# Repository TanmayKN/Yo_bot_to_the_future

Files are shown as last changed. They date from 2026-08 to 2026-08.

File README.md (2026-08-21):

<!-- Add the team photo here once it is in t-photos/, like this:
![Team Yo_Bot_To_The_Future](t-photos/team_photo.jpg)
-->

# Yo_Bot_To_The_Future

**WRO Future Engineers 2026, Self-Driving Cars**

GitHub repository and vehicle design for Team Yo_Bot_To_The_Future, Yolabs Academy.

---

## Table of Contents

- [Overview](#overview)
- [Repository Structure](#repository-structure)
- [Key Features](#key-features)
- [Key Folders](#key-folders)
- [Meet the Team](#meet-the-team)
- [Hardware](#hardware)
- [Mobility System](#mobility-system)
- [Power System](#power-system)
- [Sensing and Vision](#sensing-and-vision)
- [Software](#software)
  * [Development Environment](#development-environment)
  * [Libraries and Dependencies](#libraries-and-dependencies)
  * [Open Round](#open-round)
  * [Obstacle Round](#obstacle-round)
  * [Seeing the Pillars](#seeing-the-pillars)
  * [Failure Handling](#failure-handling)
  * [Getting the Code Running](#getting-the-code-running)
  * [Tuning and Testing](#tuning-and-testing)
- [Safety](#safety)

---

## Overview

This repository holds the hardware, the software and all the supporting material for our WRO Future Engineers 2026 vehicle. It is a 1/10 scale self driving car that drives around a walled track it has never seen before, keeps itself straight, and in the obstacle round passes red and green pillars on the correct side.

**There is one controller on this car and it is an ESP32.** No second computer, no companion board, nothing else running code. A camera usually needs a computer attached to it to make sense of what it sees, and that is normally what forces teams into a two board setup. We avoided that by using a camera that already has a processor inside it. The HuskyLens does its own colour recognition on its own chip and sends the ESP32 nothing but a handful of numbers over I2C. The picture never leaves the camera.

That one decision made a lot of other things easier. Nothing is competing with us for control of the timing, there is no boot sequence to wait through before the car is ready, there is no extra battery branch to plan around, and there is no link between two boards that can shake loose halfway through a run. What we gave up is the ability to write our own image processing code, and we were happy to trade that for a frame rate that stays the same every single time.

We run two separate programs, one for each round, rather than one program that tries to do both. The open round never needs to see a pillar, so loading it with vision code would only give it more ways to go wrong.

---

## Repository Structure

| Directory | What is inside |
| --- | --- |
| [`src/`](src/) | The ESP32 code. One program for the open round and one for the obstacle round. |
| [`models/`](models/) | STL files for every part we 3D printed, including the chassis, the cages, the wheel covers and the HuskyLens mount. |
| [`schemes/`](schemes/) | Wiring diagrams and pinout diagrams for both rounds. |
| [`t-photos/`](t-photos/) | Photos of the team. |
| [`v-photos/`](v-photos/) | Photos of the finished car from the front, back, both sides, top and bottom. |
| [`video/`](video/) | A link to our driving footage. Being filmed, going up soon. |
| [`docs/`](docs/) | The full engineering documentation. |

---

## Key Features

**One board runs the whole car.** The ESP32 reads every sensor, decides what to do, and drives the motor and the steering itself. Putting the vision inside the camera instead of on a separate computer removed a whole set of timing and power problems before they could happen.

**You can actually rebuild it from this repo.** Every printed part is here as an STL, every wire is on the diagram, and every choice we made has the reason written next to it. You should not have to guess at anything or design a part yourself.

**Two different ways of sensing the track.** The IMU tells us which way we are pointing and the ultrasonic sensors tell us where the walls are. They go wrong in completely different situations, so when one gets confused the other usually still works.

**Built for the actual rules.** The code, the wiring and the chassis are all designed around the WRO Future Engineers rules, including proper Ackermann steering on a steered front axle instead of taking the easy way out with skid steering.

---

## Key Folders

**[`src/`](src/)** has both programs, written in C++ for the Arduino framework. `open_round.ino` handles the three lap open challenge and `obstacle_challenge.ino` handles the pillar round.

**[`models/`](models/)** has every 3D printed part as an STL, ready to drop into a slicer. The chassis is meant to be printed in PETG at 30 percent honeycomb infill.

**[`schemes/`](schemes/)** has the wiring diagram for each round plus a pinout diagram showing which GPIO does what.

**[`v-photos/`](v-photos/)** has photos of the finished car from every angle. They are meant to be used as a build reference, so you can see where things actually sit and how the wires are routed instead of working from the diagram alone.

---

## Meet the Team

- **Team:** Yo_Bot_To_The_Future
- **Country:** India
- **City:** Bengaluru, Karnataka
- **Academy:** Yolabs
- **Mentor:** Rahul Sharma

| Member | School | Grade |
| --- | --- | --- |
| Vedant | Greenwood High International School | 9 |
| Tanmay | Greenwood High International School | 9 |
| Anshuman | Primus Public School | 9 |

All three of us are in Grade 9 and based in Bengaluru, and we build at Yolabs Academy under our mentor Rahul Sharma.

Two of us are from Greenwood High and one is from Primus, so we could not just meet up after class every day and work on it together. That meant we had to actually split the work up and agree on who was doing what, instead of all three of us poking at the same thing at once.

Vedant did the 3D design work, so every printed part on the car came out of his CAD files, and he also wrote the documentation and was on build duty. Tanmay wrote the code and also worked on putting the car together. Anshuman did a huge amount of the actual building, and a lot of the car physically existing is down to him.

The build itself was the part all three of us ended up working on together, which made sense, because it is the part where you find out whether the design and the code actually agree with each other.

---

## Hardware

Before building anything we worked out what parts we needed and why. Every component on this list is doing a specific job. Nothing here is just whatever we had lying around.

| Component | What it does |
| --- | --- |
| **ESP32 WROOM-32 DevKit V1** | The only controller on the car. It reads every sensor, decides what to do, and drives the motor and steering. |
| **HuskyLens AI camera** | The vision system, used in the obstacle round. Its own chip spots the coloured pillars and sends back just their position, so the ESP32 never deals with picture data. |
| **BNO055 IMU** | Tells us which way the car is facing. This is the main sensor the steering works from, and it is what stops small errors from adding up into the car driving crooked. |
| **DC drive motor** | Drives the rear wheels through the L298N. Speed is set in software as a PWM value rather than running flat out. |
| **Steering servo** | Steers the front wheels. Centre is 90 degrees with a usable range of roughly 28 to 142. |
| **PCA9685 servo driver** | Fitted to the car and sitting on the I2C bus. See the note under [Mobility System](#mobility-system) about how the steering is currently driven. |
| **3× HC-SR04 ultrasonic sensors** | Mounted front, left and right to measure how far away the walls are. The front one decides when to turn, the side ones tell us which way the track opens up. |
| **L298N motor driver** | Takes the small signals from the ESP32 and switches the much bigger current the motor needs, in both directions. |
| **LM2596 buck converters** | Drop the battery voltage down to a clean supply for the servo and the electronics, on separate branches. |
| **3S 18650 pack** | Three cells in series, about 11.1 V normally and 12.6 V when full, with a BMS. |

Other bits: PETG filament, M3 standoffs and screws, perfboard, and resistors for the voltage dividers on the ECHO lines.

---

## Mobility System

**Steering.** The front wheels are steered through an Ackermann linkage. Centre is 90 degrees, and the code clamps the travel to between 28 and 142 degrees so the linkage can never be driven into its own hard stops.

> **Note on the PCA9685.** The board is fitted and wired onto the I2C bus, but in the firmware as it stands the steering pulse is generated by the ESP32 itself on GPIO 4 using the `ESP32Servo` library. Both programs create a `Servo` object and call `attach(4)`, and neither one includes a PCA9685 library or writes to it. So the driver is present on the car but is not what moves the steering right now. If you are rebuilding from this repo, wire the servo signal to GPIO 4 and it will work.

**Drive.** A DC motor drives the rear axle through the L298N, so steering and power are separate jobs and neither has to compromise for the other. Speed is a PWM value between 0 and 255. We cruise at 150 in the open round and 135 in the obstacle round, and drop to 120 when reversing.

**Why Ackermann.** This is the same steering real cars use. When a car turns, the inside wheel is going around a tighter circle than the outside wheel. If you turn both wheels by the same amount, one of them has to slide sideways across the ground to keep up. Ackermann turns the inside wheel further than the outside one, so both wheels roll cleanly around the same point. The other option, skid steering, makes the wheels slide on purpose, and all that sliding creates friction that changes from run to run. Once that happens you can no longer predict where the car will end up. The linkage is built to satisfy this:

```
cot(Outer_Angle) - cot(Inner_Angle) = Track_Width / Wheelbase
```

**Why we do not just drive flat out.** The HuskyLens gives us a limited number of frames per second. The faster the car moves, the further it travels between one frame and the next, which means every decision about a pillar is based on a picture of where things were a moment ago. Slowing the car down until it matches the camera is easier and more reliable than trying to speed the camera up. The same logic applies to the ultrasonics, which need time for the sound to travel out and come back.

---

## Power System

The car runs on three lithium ion cells in series, which is about 11.1 V normally and 12.6 V when fully charged. The power splits right after a master fuse and a kill switch into branches that do not share a wire.

```mermaid
flowchart LR
    BAT[3S 18650 pack<br/>12.6V full] --> FUSE[Master fuse<br/>+ kill switch]

    FUSE -->|raw 12.6V| L298[L298N driver]
    L298 --> MOT[Drive motor]

    FUSE -->|buck| SRV[Steering servo]
    FUSE -->|buck to 5V| ESP[ESP32]
    FUSE -->|buck to 5V| HL[HuskyLens]
```

**Why separate branches.** The motor wants the full battery voltage and pulls a lot of current when it speeds up. The servo briefly pulls over an amp if it pushes against something and gets stuck. If either of those shared a wire with the electronics, the voltage would dip enough to reset the ESP32 in the middle of a run. The annoying part is that this looks exactly like a software bug when you are trying to find it.

**Something worth knowing if you rebuild this:** the HuskyLens pulls around 320 mA while it is working. That is more than you want to run through the ESP32's own 5 V pin, so it should be fed from the regulated supply instead.

---

## Sensing and Vision

```mermaid
flowchart LR
    UL[Left ultrasonic] --> ESP[ESP32]
    UF[Front ultrasonic] --> ESP
    UR[Right ultrasonic] --> ESP

    HL[HuskyLens] -->|I2C, block coords| ESP
    IMU[BNO055] -->|I2C| ESP
    PCA[PCA9685] -.->|I2C, fitted| ESP
    ESP -->|GPIO 4 PWM| SRV[Steering servo]
    ESP --> L298[L298N] --> MOT[Drive motor]
```

**BNO055 IMU.** This is the sensor the steering really works from. It does its own sensor fusion and gives us a heading straight out, so we are not writing filter code ourselves. Steering by heading rather than by wall distance means the car keeps going straight even when a wall reading is briefly wrong.

**Ultrasonics.** One at the front and one on each side. The front sensor decides when a wall is close enough to turn at, and the side sensors tell us which way the track opens up so we know which direction to turn. They also catch the case where the car is about to hit something and needs to back up.

**HuskyLens.** Used in the obstacle round only, mounted on a printed bracket so it can see the pillars ahead. It sits on the I2C bus alongside the IMU and the PCA9685.

**A wiring warning.** The ECHO pins on the HC-SR04 put out 5 V, and the ESP32's pins can only take 3.3 V. Every ECHO line goes through a voltage divider. If you skip this you will damage the board.

### Pin map

Both programs use the same wiring, so you do not have to change anything on the car between rounds.

| Function | ESP32 pin |
| --- | --- |
| Motor direction | GPIO 13, GPIO 12 |
| Motor PWM | GPIO 25 |
| Steering servo signal | GPIO 4 |
| Front ultrasonic TRIG / ECHO | GPIO 5 / 18 |
| Right ultrasonic TRIG / ECHO | GPIO 17 / 16 |
| Left ultrasonic TRIG / ECHO | GPIO 26 / 27 |
| Start button | GPIO 15, active low |
| I2C bus for BNO055, HuskyLens and PCA9685 | GPIO 21 SDA, GPIO 22 SCL |

`Wire.begin()` is called with no arguments in both programs, which is what puts the I2C bus on GPIO 21 and 22. Everything shares one common ground.

---

## Software

### Development Environment

| Part | Language | Written and flashed with |
| --- | --- | --- |
| ESP32 | C++ / Arduino | Arduino IDE 2.0 or newer, with the ESP32 board package by Espressif |

The board is set up as an **ESP32 Dev Module**, with the serial monitor at 115200.

### Libraries and Dependencies

| Library | Used by | Why it is needed |
| --- | --- | --- |
| `Adafruit_BNO055` and `Adafruit_Sensor` | Both | Reads the heading out of the IMU. |
| `ESP32Servo` | Both | Generates the steering pulse straight off a GPIO pin. |
| `Wire` | Both | I2C. Already comes with the Arduino IDE. |
| `HUSKYLENS` | Obstacle round | Talks to the camera over I2C and turns what comes back into something we can use. |
| `WiFi` | Open round | Only used for the optional telnet debug link. |

### Open Round

Three laps around an empty track, then back to where it started.

The car steers by heading rather than by wall distance. The BNO055 gives us the angle we are actually pointing at, we compare it to the angle we want, and a **PI controller** turns that difference into a small steering correction:

```
Error      = Target_Heading - Current_Heading
Correction = GAIN_P * Error + GAIN_I * Integral(Error)
```

`GAIN_P` is 6.0 and decides how hard the car reacts to being off angle right now. `GAIN_I` is 0.2 and slowly removes any drift that builds up over a lap. The correction is capped at 22 degrees so a bad reading can never throw the steering hard over, and the integral has its own separate cap of 150 to stop it winding up. Any error under 0.6 degrees counts as straight and gets ignored, otherwise the car would twitch constantly.

There is no D term. On a car this size the P and I terms were enough, and adding D mostly amplified noise.

The front ultrasonic decides when to corner. Below 65 cm the car commits to a turn, and the side sensors decide which way by looking for the gap over 90 cm. Below 25 cm the car has got too close, so it reverses for about 700 ms and tries again. The PI controller is switched off during a corner, because during a deliberate turn a large heading error is correct and letting the controller fight it would only make the turn worse.

Once three laps are done the car switches into homing mode, which is the same wall following with looser thresholds, and stops when the front distance comes back within 5 cm of what it measured at the start line.

```mermaid
flowchart TD
    A([Power on]) --> B[Wait for START over serial]
    B --> C[Read heading and<br/>all three ultrasonics]
    C --> H{homingMode?}
    H -->|Yes| HM[Head for the start line]
    HM --> C
    H -->|No| D{Front wall<br/>under 25 cm?}
    D -->|Yes| E[Reverse 700 ms]
    E --> C
    D -->|No| F{Front under 65 cm and<br/>one side open over 90 cm?}
    F -->|Yes| G[Back up, corner left or right]
    G --> C
    F -->|No| I[Cruise at PWM 150,<br/>PI controller holds heading]
    I --> C
```

### Obstacle Round

Same track, now with red and green pillars that have to be passed on the correct side.

The program runs as a two state machine. While the state is `STRAIGHT` the camera gets a say. Once the car commits to a turn the state becomes `TURNING` and the camera is ignored completely until the turn is finished, because half a decision from a camera partway through a turn is worse than no decision at all.

When the camera reports a pillar that is close enough to matter, the car overrides its normal steering and shifts to one side to go around it, then hands control back once it is past. Two numbers decide whether a pillar counts. `HUSKY_AREA_TRIGGER` is 3000 and is how big the pillar has to look before the car commits to a full dodge, since a bigger block means a closer pillar. `HUSKY_SOFT_TRIGGER` is 150 and catches pillars that are further away, so the car can start lining up early instead of swerving at the last second.

After a pillar is dealt with there is a cooldown of roughly 1.8 seconds before the car will react to another one. Without it, the same pillar gets seen again on the next frame and the car tries to avoid something it has already passed. If a wall turns up while that cooldown is still running, the car creeps forward slowly rather than turning, and if it ends up jammed against the wall it reverses out.

Before a turn actually starts there is a second gate. The car stops, reads the wall again to confirm, and checks one last time that no pillar is in view. If either check fails the turn is abandoned. The run ends after 12 turns, which is three laps of a four cornered track.

### Seeing the Pillars

The HuskyLens is used in Colour Recognition mode with three colours taught to it:

| ID | Colour | What it means |
| --- | --- | --- |
| 1 | Green | Pass on one side |
| 2 | Red | Pass on the other side |
| 3 | Magenta | The parking lot, ignored during normal driving |

It saves these in its own memory, so they stay there after the power is turned off and we do not have to teach it again every time.

Each frame it sends back the biggest matching patch of colour as a block, which is an ID, a centre X, a centre Y, a width and a height. The ESP32 gets two useful things out of that. The centre X tells us which side of the frame the pillar is on, measured against 160 on a 320 pixel wide image. The size of the block tells us roughly how far away it is. Between the soft and the hard trigger the steering nudge is scaled from 8 to 35 degrees depending on both, so a pillar that is far away and near the middle barely moves the wheels while one that is close and off to the side gets a firm response.

Because the camera does the recognising itself, it works on hue rather than raw RGB, which holds up much better when the lighting at the venue is not the lighting we practised in.

### Failure Handling

Most of what went wrong in testing was not the car making a bad decision. It was the car making a decision based on information that was no longer true.

- **A wall reading that makes no sense.** Ultrasonic sound that hits a wall at a sharp angle never comes back, and the sensor just times out. Because the car steers by IMU heading and not by wall distance, one bad reading does not move the steering at all. It only affects when the car decides to corner, and the obstacle program reads the wall a second time to confirm before committing.
- **Getting too close to a wall.** The car stops trying to steer out of it, reverses, and starts again. Trying to steer out of a corner you are already in usually just wedges the car in harder.
- **Seeing the same pillar twice.** The cooldown after an avoidance stops the car reacting again to a pillar it has already gone around.
- **Lighting changes.** Arena lighting washes the colours out. The fix is to teach the colours again once we get to the venue, under the lights we are actually going to run under.

### Getting the Code Running

1. Clone the repo and open either `src/open_round.ino` or `src/obstacle_challenge.ino` in the Arduino IDE.
2. Install the libraries listed above through the Library Manager.
3. For the obstacle round, go into the HuskyLens settings menu and set the protocol to **I2C**. Put it in **Colour Recognition** mode and teach it green as ID 1, red as ID 2 and magenta as ID 3. Do this under the lighting you are actually going to run in.
4. Pick **ESP32 Dev Module** as the board, choose your serial port, and upload.
5. Open the serial monitor at 115200 and check the I2C devices are found.
6. Put the car up on blocks with the wheels off the ground. Check the motor spins the right way, the steering centres, and the IMU heading changes when you rotate the car by hand.
7. Send `START` over the serial monitor to begin the open round.

### Tuning and Testing

**What to tune, in this order:**

1. **Steering centre.** `STEER_CENTRE` is 94 in the open round and needs trimming for each car, because no two linkages come out identical. Get this right first, since everything else is built on top of a car that drives straight.
2. **Colour IDs.** Teach them again at the venue, every time. This is the number one reason pillars get missed.
3. **Pillar triggers.** `HUSKY_AREA_TRIGGER` decides how close a pillar gets before the car commits. Set it too low and the car swerves at pillars it has not even reached yet.
4. **PI gains.** `GAIN_P` first, until the car holds a straight line without weaving. Then `GAIN_I`, and keep it small, since its job is only to remove slow drift over a lap.
5. **Corner distances.** `RANGE_CORNER` at 65 cm decides when the car starts turning. Too late and it clips the wall, too early and it cuts the corner short.

The open round also has an optional telnet debug link over WiFi, so you can watch what the car is thinking while it drives instead of trailing a USB cable behind it. Put your network details in `WIFI_SSID` and `WIFI_PASS` and uncomment `startDebugLink()` in `setup()`.

---

## Safety

A 3S lithium battery holds enough energy to start a fire, and the steering has enough force to pinch a finger. These are the rules we work to.

- The pack is charged on a balance charger, on a surface that will not burn, never left alone and never inside a closed box.
- A master fuse sits on the positive wire from the battery, so a short further down blows the fuse instead of pushing the battery's full current through the wiring. The kill switch cuts every branch and can be reached from outside the chassis.
- The battery gets unplugged before any rewiring, and metal tools stay away from the battery terminals.
- Buck converters get checked with a multimeter before any board is plugged into them. One set wrong will kill the ESP32 and the HuskyLens instantly.
- Keep fingers away from the steering while the car is powered. The servo can jump without warning if the ESP32 resets.
- All motor code gets tested with the car up on blocks and the wheels off the ground.

The full list is in section 2.5 of the engineering documentation in [`docs/`](docs/).

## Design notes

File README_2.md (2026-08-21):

<!-- Add the team photo here once it is in t-photos/, like this:
![Team Yo_Bot_To_The_Future](t-photos/team_photo.jpg)
-->

# Yo_Bot_To_The_Future

**WRO Future Engineers 2026, Self-Driving Cars**

GitHub repository and vehicle design for Team Yo_Bot_To_The_Future, Yolabs Academy.

---

## Table of Contents

- [Overview](#overview)
- [Repository Structure](#repository-structure)
- [Key Features](#key-features)
- [Key Folders](#key-folders)
- [Meet the Team](#meet-the-team)
- [Hardware](#hardware)
- [Mobility System](#mobility-system)
- [Power System](#power-system)
- [Sensing and Vision](#sensing-and-vision)
- [Software](#software)
  * [Development Environment](#development-environment)
  * [Libraries and Dependencies](#libraries-and-dependencies)
  * [Open Round](#open-round)
  * [Obstacle Round](#obstacle-round)
  * [Seeing the Pillars](#seeing-the-pillars)
  * [Failure Handling](#failure-handling)
  * [Getting the Code Running](#getting-the-code-running)
  * [Tuning and Testing](#tuning-and-testing)
- [Safety](#safety)

---

## Overview

This repository holds the hardware, the software and all the supporting material for our WRO Future Engineers 2026 vehicle. It is a 1/10 scale self driving car that drives around a walled track it has never seen before, keeps itself straight, and in the obstacle round passes red and green pillars on the correct side.

**Everything runs on one board.** A camera normally needs a computer to go with it, so most teams add a single board computer to handle the obstacle round. We did it the other way around and used a camera that has a computer inside it. The HuskyLens does its own colour recognition on its own chip and only sends us back a few numbers over I2C. All the heavy work with the picture happens inside the camera, so our ESP32 never has to touch it.

That one choice made a lot of other things easier. There is no operating system fighting us for control of the timing, no waiting for a computer to boot before we can start, no extra battery branch to plan for, and no cable between two boards that can shake loose halfway through a run. What we gave up is the ability to write our own image code, and we were happy to trade that for a frame rate that stays the same every single time.

We run two separate programs, one for each round, rather than one program that tries to do both. The open round never needs to see a pillar, so loading it with vision code would only give it more ways to fail.

---

## Repository Structure

| Directory | What is inside |
| --- | --- |
| [`src/`](src/) | The ESP32 code. One program for the open round and one for the obstacle round. |
| [`models/`](models/) | STL files for every part we 3D printed, including the chassis, the cages, the wheel covers and the HuskyLens mount. |
| [`schemes/`](schemes/) | Wiring diagrams for both rounds, showing every part and how it all connects. |
| [`t-photos/`](t-photos/) | Photos of the team. |
| [`v-photos/`](v-photos/) | Photos of the finished car from the front, back, both sides, top and bottom. |
| [`video/`](video/) | A link to our driving footage. Being filmed, going up soon. |
| [`docs/`](docs/) | The full engineering documentation. |

---

## Key Features

**One controller for the whole car.** The ESP32 reads every sensor, decides what to do and drives the motor and steering itself. Vision lives inside the camera instead of on a second board, which removed a whole set of timing and power problems before they could happen.

**You can actually rebuild it from this repo.** Every printed part is here as an STL, every wire is on the diagram, and every choice we made has the reason written next to it. You should not have to guess at anything or design a part yourself.

**Two different ways of sensing the track.** The IMU tells us which way we are pointing and the ultrasonic sensors tell us where the walls are. They fail in completely different situations, so when one gets confused the other usually still works.

**Built for the actual rules.** The code, the wiring and the chassis are all designed around the WRO Future Engineers rules, including proper Ackermann steering on a steered front axle instead of taking the easy way out with skid steering.

---

## Key Folders

**[`src/`](src/)** has both programs, written in C++ for the Arduino framework. `open_round.ino` handles the three lap open challenge and `obstacle_challenge.ino` handles the pillar round.

**[`models/`](models/)** has every 3D printed part as an STL, ready to drop into a slicer. The chassis is meant to be printed in PETG at 30 percent honeycomb infill.

**[`schemes/`](schemes/)** has a wiring diagram for each round. They show the full power layout starting from the battery, which branch each part sits on, and which sensor lines need voltage dividers.

**[`v-photos/`](v-photos/)** has photos of the finished car from every angle. They are meant to be used as a build reference, so you can see where things actually sit and how the wires are routed instead of working from the diagram alone.

---

## Meet the Team

- **Team:** Yo_Bot_To_The_Future
- **Country:** India
- **City:** Bengaluru, Karnataka
- **Academy:** Yolabs
- **Mentor:** Rahul Sharma

| Member | School | Grade |
| --- | --- | --- |
| Vedant | Greenwood High International School | 9 |
| Tanmay | Greenwood High International School | 9 |
| Anshuman | Primus Public School | 9 |

All three of us are in Grade 9 and based in Bengaluru, and we build at Yolabs Academy under our mentor Rahul Sharma.

Two of us are from Greenwood High and one is from Primus, so we could not just meet up after class every day and work on it together. That meant we had to actually split the work up and agree on who was doing what, instead of all three of us poking at the same thing at once.

Vedant did the 3D design work, so every printed part on the car came out of his CAD files, and he also wrote the documentation and was on build duty. Tanmay wrote the code and also worked on putting the car together. Anshuman did a huge amount of the actual building, and a lot of the car physically existing is down to him.

The build itself was the part all three of us ended up working on together, which made sense, because it is the part where you find out whether the design and the code actually agree with each other.

---

## Hardware

Before building anything we worked out what parts we needed and why. Every component on this list is doing a specific job. Nothing here is just whatever we had lying around.

| Component | What it does |
| --- | --- |
| **ESP32 WROOM-32 DevKit V1** | The only controller on the car. It reads every sensor, decides what to do, and drives the motor and steering. |
| **HuskyLens AI camera** | The vision system, used in the obstacle round. Its own chip spots the coloured pillars and sends back just their position, so the ESP32 never deals with picture data. |
| **BNO055 IMU** | Tells us which way the car is facing. This is the main sensor the open round steers by, and it is what stops small errors from adding up into the car driving crooked. |
| **DC drive motor** | Drives the rear wheels through the L298N. Speed is set in software as a PWM value rather than running flat out. |
| **Steering servo** | Steers the front wheels, driven straight off the ESP32 with the `ESP32Servo` library. Centre is 90 degrees with a usable range of roughly 28 to 142. |
| **3× HC-SR04 ultrasonic sensors** | Mounted front, left and right to measure how far away the walls are. The front one decides when to turn, the side ones tell us which way the track opens up. |
| **L298N motor driver** | Takes the small signals from the ESP32 and switches the much bigger current the motor needs, in both directions. |
| **LM2596 buck converters** | Drop the battery voltage down to a clean supply for the servo and the electronics, on separate branches. |
| **3S 18650 pack** | Three cells in series, about 11.1 V normally and 12.6 V when full, with a BMS. |

Other bits: PETG filament, M3 standoffs and screws, perfboard, and resistors for the voltage dividers on the ECHO lines.

---

## Mobility System

**Steering.** The front wheels are steered through an Ackermann linkage. The servo is driven directly from GPIO 4 using `ESP32Servo`, with 90 degrees as centre.

**Drive.** A DC motor drives the rear axle through the L298N, so steering and power are separate jobs and neither has to compromise for the other. Speed is a PWM value between 0 and 255. We cruise at 150 in the open round and 135 in the obstacle round, and drop to 120 when reversing.

**Why Ackermann.** This is the same steering real cars use. When a car turns, the inside wheel is going around a tighter circle than the outside wheel. If you turn both wheels by the same amount, one of them has to slide sideways across the ground to keep up. Ackermann turns the inside wheel further than the outside one, so both wheels roll cleanly around the same point. The other option, skid steering, makes the wheels slide on purpose, and all that sliding creates friction that changes from run to run. Once that happens you can no longer predict where the car will end up. The linkage is built to satisfy this:

```
cot(Outer_Angle) - cot(Inner_Angle) = Track_Width / Wheelbase
```

**Why we do not just drive flat out.** The HuskyLens gives us a limited number of frames per second. The faster the car moves, the further it travels between one frame and the next, which means every decision about a pillar is based on a picture of where things were a moment ago. Slowing the car down until it matches the camera is easier and more reliable than trying to speed the camera up. The same logic applies to the ultrasonics, which need time for the sound to travel out and come back.

---

## Power System

The car runs on three lithium ion cells in series, which is about 11.1 V normally and 12.6 V when fully charged. The power splits right after a master fuse and a kill switch into branches that do not share a wire.

```mermaid
flowchart LR
    BAT[3S 18650 pack<br/>12.6V full] --> FUSE[Master fuse<br/>+ kill switch]

    FUSE -->|raw 12.6V| L298[L298N driver]
    L298 --> MOT[Drive motor]

    FUSE -->|buck| SRV[Steering servo]
    FUSE -->|buck to 5V| ESP[ESP32]
    FUSE -->|buck to 5V| HL[HuskyLens]
```

**Why separate branches.** The motor wants the full battery voltage and pulls a lot of current when it speeds up. The servo briefly pulls over an amp if it pushes against something and gets stuck. If either of those shared a wire with the electronics, the voltage would dip enough to reset the ESP32 in the middle of a run. The annoying part is that this looks exactly like a software bug when you are trying to find it.

**Something worth knowing if you rebuild this:** the HuskyLens pulls around 320 mA while it is working. That is more than you want to run through the ESP32's own 5 V pin, so it should be fed from the regulated supply instead.

---

## Sensing and Vision

```mermaid
flowchart LR
    UL[Left ultrasonic] --> ESP[ESP32]
    UF[Front ultrasonic] --> ESP
    UR[Right ultrasonic] --> ESP

    HL[HuskyLens] -->|I2C, block coords| ESP
    IMU[BNO055] -->|I2C| ESP
    ESP -->|GPIO 4| SRV[Steering servo]
    ESP --> L298[L298N] --> MOT[Drive motor]
```

**BNO055 IMU.** This is the sensor the open round is really built around. It does its own sensor fusion and gives us a heading straight out, so we are not writing filter code ourselves. Steering by heading rather than by wall distance means the car keeps going straight even when a wall reading is briefly wrong.

**Ultrasonics.** One at the front and one on each side. The front sensor decides when a wall is close enough to turn at, and the side sensors tell us which way the track opens up so we know which direction to turn. They also catch the case where the car is about to hit something and needs to back up.

**HuskyLens.** Used in the obstacle round only, mounted on a printed bracket so it can see the pillars ahead. It sits on the I2C bus alongside the IMU.

**A wiring warning.** The ECHO pins on the HC-SR04 put out 5 V, and the ESP32's pins can only take 3.3 V. Every ECHO line goes through a voltage divider. If you skip this you will damage the board.

### Pin map

Both programs use the same wiring, so you do not have to change anything on the car between rounds.

| Function | ESP32 pin |
| --- | --- |
| Motor direction | GPIO 13, GPIO 12 |
| Motor PWM | GPIO 25 |
| Steering servo | GPIO 4 |
| Front ultrasonic TRIG / ECHO | GPIO 5 / 18 |
| Right ultrasonic TRIG / ECHO | GPIO 17 / 16 |
| Left ultrasonic TRIG / ECHO | GPIO 26 / 27 |
| Start button | GPIO 15, active low |
| BNO055 and HuskyLens | I2C |

Everything shares one common ground.

---

## Software

### Development Environment

| Part | Language | Written and flashed with |
| --- | --- | --- |
| ESP32 | C++ / Arduino | Arduino IDE 2.0 or newer, with the ESP32 board package by Espressif |

The board is set up as an **ESP32 Dev Module**, with the serial monitor at 115200.

### Libraries and Dependencies

| Library | Used by | Why it is needed |
| --- | --- | --- |
| `Adafruit_BNO055` and `Adafruit_Sensor` | Both | Reads the heading out of the IMU. |
| `ESP32Servo` | Both | Drives the steering servo directly off a GPIO pin. |
| `Wire` | Both | I2C. Already comes with the Arduino IDE. |
| `HUSKYLENS` | Obstacle round | Talks to the camera over I2C and turns what comes back into something we can use. |
| `WiFi` | Open round | Only used for the telnet debug link, which is optional. |

### Open Round

Three laps around an empty track, then back to where it started.

The car steers by heading rather than by wall distance. The BNO055 gives us the angle we are actually pointing at, we compare it to the angle we want, and a **PI controller** turns that difference into a small steering correction:

```
Error      = Target_Heading - Current_Heading
Correction = GAIN_P * Error + GAIN_I * Integral(Error)
```

`GAIN_P` is 6.0 and decides how hard the car reacts to being off angle right now. `GAIN_I` is 0.2 and slowly removes any drift that builds up over a lap. The correction is capped at 22 degrees so a bad reading can never throw the steering hard over, and the integral has its own separate cap to stop it winding up. Any error under 0.6 degrees counts as straight and gets ignored, otherwise the car would twitch constantly.

There is no D term. On a car this size the P and I terms were enough, and adding D mostly amplified noise from the ultrasonics.

The front ultrasonic decides when to corner. Below 65 cm the car commits to a turn, and the side sensors decide which way by looking for the gap over 90 cm. Below 25 cm the car has got too close, so it reverses for about 700 ms and tries again. The PI controller is switched off during a corner, because during a deliberate turn a large heading error is correct and letting the controller fight it would make the turn worse.

```mermaid
flowchart TD
    A([Power on]) --> B[Start command over serial]
    B --> C[Read heading and<br/>all three ultrasonics]
    C --> D{Front wall<br/>under 25 cm?}
    D -->|Yes| E[Reverse, straighten]
    E --> C
    D -->|No| F{Front wall<br/>under 65 cm?}
    F -->|Yes| G[Pick a side from the gaps,<br/>turn, PI controller off]
    G --> C
    F -->|No| H[PI controller<br/>holds the heading]
    H --> I{Three laps done?}
    I -->|No| C
    I -->|Yes| J([Return to start and stop])
```

### Obstacle Round

Same track, now with red and green pillars that have to be passed on the correct side.

The car uses the same heading control and the same wall logic as the open round, and the HuskyLens sits on top of that. When the camera reports a pillar that is close enough to matter, the car overrides its normal steering and shifts to one side to go around it, then hands control back once it is past.

Two numbers decide whether a pillar counts. `HUSKY_AREA_TRIGGER` is 3000 and is how big the pillar has to look before the car commits to going around it, since a bigger block means a closer pillar. `HUSKY_SOFT_TRIGGER` is 150 and catches pillars that are further away, so the car can start lining up early instead of swerving at the last second.

After a pillar is dealt with there is a cooldown of roughly 1.8 seconds before the car will react to another one. Without it, the same pillar gets seen again on the next frame and the car tries to avoid something it has already passed.

The run ends after 12 turns, which is three laps of a four cornered track.

### Seeing the Pillars

The HuskyLens is used in Colour Recognition mode with three colours taught to it:

| ID | Colour | What it means |
| --- | --- | --- |
| 1 | Green | Pass on one side |
| 2 | Red | Pass on the other side |
| 3 | Magenta | The parking lot, ignored during normal driving |

It saves these in its own memory, so they stay there after the power is turned off and we do not have to teach it again every time.

Each frame it sends back the biggest matching patch of colour as a block, which is an ID, a centre X, a centre Y, a width and a height. The ESP32 gets two useful things out of that. The centre X tells us which side of the frame the pillar is on. The size of the block tells us roughly how far away it is, since a pillar that takes up more of the picture must be closer. The colour decides which way we go and the size decides when we commit.

Because the camera does the recognising itself, it works on hue rather than raw RGB, which holds up much better when the lighting at the venue is not the lighting we practised in.

### Failure Handling

Most of what went wrong in testing was not the car making a bad decision. It was the car making a decision based on information that was no longer true.

- **A wall reading that makes no sense.** Ultrasonic sound that hits a wall at a sharp angle never comes back, and the sensor just times out. Because the car steers by IMU heading and not by wall distance, one bad reading does not move the steering at all. It only affects when the car decides to corner, and that needs the reading to be wrong consistently rather than once.
- **Getting too close to a wall.** Below 25 cm the car stops trying to steer out of it, reverses for about 700 ms and starts again. Trying to steer out of a corner you are already in usually just wedges the car harder.
- **Seeing the same pillar twice.** The cooldown after an avoidance stops the car reacting again to a pillar it has already gone around.
- **Lighting changes.** Arena lighting washes the colours out. The fix is to teach the colours again once we get to the venue, under the lights we are actually going to run under.

### Getting the Code Running

1. Clone the repo and open either `src/open_round.ino` or `src/obstacle_challenge.ino` in the Arduino IDE.
2. Install the libraries listed above through the Library Manager.
3. For the obstacle round, go into the HuskyLens settings menu and set the protocol to **I2C**. Put it in **Colour Recognition** mode and teach it green as ID 1, red as ID 2 and magenta as ID 3. Do this under the lighting you are actually going to run in.
4. Pick **ESP32 Dev Module** as the board, choose your serial port, and upload.
5. Open the serial monitor at 115200.
6. Put the car up on blocks with the wheels off the ground. Check the motor spins the right way, the steering centres at 90 degrees, and the IMU heading changes when you rotate the car by hand.
7. Send `START` over the serial monitor to begin the run.

### Tuning and Testing

**What to tune, in this order:**

1. **Steering centre.** `STEER_CENTRE` is 94 in the open round and needs trimming for each car, because no two linkages come out identical. Get this right first, since everything else is built on top of a car that drives straight.
2. **Colour IDs.** Teach them again at the venue, every time. This is the number one reason pillars get missed.
3. **Pillar triggers.** `HUSKY_AREA_TRIGGER` decides how close a pillar gets before the car commits. Set it too low and the car swerves at pillars it has not even reached yet.
4. **PI gains.** `GAIN_P` first, until the car holds a straight line without weaving. Then `GAIN_I`, and keep it small, since its job is only to remove slow drift over a lap.
5. **Corner distances.** `RANGE_CORNER` at 65 cm decides when the car starts turning. Too late and it clips the wall, too early and it cuts the corner short.

The open round also has an optional telnet debug link over WiFi, so you can watch what the car is thinking while it drives instead of trailing a USB cable behind it. Put your network details in `WIFI_SSID` and `WIFI_PASS` and uncomment `startDebugLink()` in `setup()`.

---

## Safety

A 3S lithium battery holds enough energy to start a fire, and the steering has enough force to pinch a finger. These are the rules we work to.

- The pack is charged on a balance charger, on a surface that will not burn, never left alone and never inside a closed box.
- A master fuse sits on the positive wire from the battery, so a short further down blows the fuse instead of pushing the battery's full current through the wiring. The kill switch cuts every branch and can be reached from outside the chassis.
- The battery gets unplugged before any rewiring, and metal tools stay away from the battery terminals.
- Buck converters get checked with a multimeter before any board is plugged into them. One set wrong will kill the ESP32 and the HuskyLens instantly.
- Keep fingers away from the steering while the car is powered. The servo can jump without warning if the ESP32 resets.
- All motor code gets tested with the car up on blocks and the wheels off the ground.

The full list is in section 2.5 of the engineering documentation in [`docs/`](docs/).

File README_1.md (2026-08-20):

<!-- Add the team photo here once it is in t-photos/, like this:
![Team Yo_Bot_To_The_Future](t-photos/team_photo.jpg)
-->

# Yo_Bot_To_The_Future

**WRO Future Engineers 2026, Self-Driving Cars**

GitHub repository and vehicle design for Team Yo_Bot_To_The_Future, Yolabs Academy.

---

## Table of Contents

- [Overview](#overview)
- [Repository Structure](#repository-structure)
- [Key Features](#key-features)
- [Key Folders](#key-folders)
- [Meet the Team](#meet-the-team)
- [Hardware](#hardware)
- [Mobility System](#mobility-system)
- [Power System](#power-system)
- [Sensor Integration](#sensor-integration)
- [Software](#software)
  * [Development Environment](#development-environment)
  * [Libraries and Dependencies](#libraries-and-dependencies)
  * [How the Code Works](#how-the-code-works)
  * [Seeing the Pillars](#seeing-the-pillars)
  * [Failure Handling](#failure-handling)
  * [Getting the Code Running](#getting-the-code-running)
  * [Tuning and Testing](#tuning-and-testing)
- [Safety](#safety)

---

## Overview

This repository holds the hardware, the software and all the supporting material for our WRO Future Engineers 2026 vehicle. It is a 1/10 scale self driving car that drives around a walled track it has never seen before, keeps itself in the middle of the lane, and passes red and green pillars on the correct side.

**One controller, not two.** A camera normally needs a computer to go with it, so most teams add a single board computer to handle the obstacle round. We did it the other way around and used a camera that has a computer inside it. The HuskyLens does its own colour recognition on its own chip and only sends us back a few numbers over I2C. All the heavy work with the picture happens inside the camera, so our ESP32 never has to touch it.

That one choice made a lot of other things easier. There is no operating system fighting us for control of the timing, no waiting for a computer to boot before we can start, no extra battery branch to plan for, and no cable between two boards that can shake loose halfway through a run. What we gave up is the ability to write our own image code, and we were happy to trade that for a frame rate that stays the same every single time.

---

## Repository Structure

| Directory | What is inside |
| --- | --- |
| [`src/`](src/) | The ESP32 code, plus the small test programs we wrote while getting the hardware working. |
| [`models/`](models/) | STL files for every part we 3D printed, including the chassis plates, the roof tier and the HuskyLens bracket. |
| [`schemes/`](schemes/) | The wiring diagram, showing every part and how it all connects. |
| [`t-photos/`](t-photos/) | Photos of the team. |
| [`v-photos/`](v-photos/) | Photos of the finished car from the front, back, both sides, top and bottom. |
| [`video/`](video/) | A link to our driving test footage. Being filmed, going up soon. |
| [`docs/`](docs/) | The full engineering documentation. |

---

## Key Features

**Everything runs on one board.** The whole car is controlled by a single ESP32. Putting the vision inside the camera instead of on a second board got rid of a whole set of timing and power problems before they could happen.

**You can actually rebuild it from this repo.** Every printed part is here as an STL, every wire is on the diagram, and every choice we made has the reason written next to it. You should not have to guess at anything or design a part yourself.

**Two different ways of sensing the track.** The camera works on light and the ultrasonic sensors work on sound. When glare off the mat blinds the camera, the ultrasonics keep the car going. That is the difference between one bad frame and a crash.

**Built for the actual rules.** The code, the wiring and the chassis are all designed around the WRO Future Engineers rules, including proper Ackermann steering on a steered front axle instead of taking the easy way out with skid steering.

---

## Key Folders

**[`src/`](src/)** is the full code, written in C++ for the Arduino framework. Next to the main program there are smaller test sketches we used to check each part on its own before running anything complete.

**[`models/`](models/)** has every 3D printed part as an STL, ready to drop into a slicer. The chassis is meant to be printed in PETG at 30 percent honeycomb infill.

**[`schemes/`](schemes/)** has the wiring diagram. It shows the full power layout starting from the battery, which branch each part sits on, and which sensor lines need voltage dividers.

**[`v-photos/`](v-photos/)** has photos of the finished car from every angle. They are meant to be used as a build reference, so you can see where things actually sit and how the wires are routed instead of working from the diagram alone.

---

## Meet the Team

| Member | School | Grade |
| --- | --- | --- |
| Vedant | Greenwood High International School | 9 |
| Tanmay | Greenwood High International School | 9 |
| Anshuman | Primus Public School | 9 |

Two of us are from Greenwood High and one is from Primus, so we could not just meet up after class every day and work on it together. That meant we had to actually split the work up and agree on who was doing what, instead of all three of us poking at the same thing at once.

Vedant did the 3D design work, so every printed part on the car came out of his CAD files, and he also wrote the documentation and was on build duty. Tanmay wrote the code and also worked on putting the car together. Anshuman did a huge amount of the actual building, and a lot of the car physically existing is down to him.

The build itself was the part all three of us ended up working on together, which made sense, because it is the part where you find out whether the design and the code actually agree with each other.

---

## Hardware

Before building anything we worked out what parts we needed and why. Every component on this list is doing a specific job. Nothing here is just whatever we had lying around.

| Component | What it does |
| --- | --- |
| **ESP32 WROOM-32 DevKit V1** | The only controller on the car. It reads every sensor, runs the state machine and drives the motors and steering. |
| **HuskyLens AI camera** | The vision system. Its own chip spots the red and green pillars and sends back just their position, so the ESP32 never deals with picture data. |
| **2× 100 RPM geared DC motors** | Rear wheel drive through the L298N. The speed is on purpose, and the reason is under [Mobility System](#mobility-system). |
| **MG996R metal gear servo** | Steers the front wheels. It needs to be a strong one, because the steering has to hold its angle against the tyres while the car is moving. |
| **PCA9685 servo driver** | Makes the servo pulse off the I2C bus, so the steering timing does not depend on whatever else the ESP32 is busy with. |
| **3× HC-SR04 ultrasonic sensors** | Mounted front, left and right to measure how far away the walls are. |
| **MPU-6050 IMU** | Tells us which way the car is facing. Small steering errors add up over three laps, and this is what lets us correct for that. |
| **L298N motor driver** | Takes the small signals from the ESP32 and switches the much bigger current the motors need, in both directions. |
| **2× LM2596 buck converters** | Drop the battery voltage down to a clean 6.0 V for the servo and 5.0 V for the electronics, on separate branches. |
| **Custom 3S1P 18650 pack** | Three cells in series, about 11.1 V normally and 12.6 V when full, with a 10 A BMS. |
| **4× 65 mm rubber tread wheels** | 204.2 mm around, which is the number all our distance maths is based on. |

Other bits: PETG filament, M3 standoffs and screws, perfboard, and resistors (100k, 22k, 1k, 2k) for the voltage dividers.

---

## Mobility System

**Steering.** The two front wheels are steered through an Ackermann linkage driven by the MG996R.

**Drive.** Two 100 RPM geared motors turn the rear axle, so steering and power are separate jobs and neither has to compromise for the other.

**Why Ackermann.** This is the same steering real cars use. When a car turns, the inside wheel is going around a tighter circle than the outside wheel. If you turn both wheels by the same amount, one of them has to slide sideways across the ground to keep up. Ackermann turns the inside wheel further than the outside one, so both wheels roll cleanly around the same point. The other option, skid steering, makes the wheels slide on purpose, and all that sliding creates friction that changes from run to run. Once that happens you can no longer predict where the car will end up. The linkage is built to satisfy this:

```
cot(Outer_Angle) - cot(Inner_Angle) = Track_Width / Wheelbase
```

**Turning radius.** There are physical stops built into the chassis that limit how far the steering can travel, capping it at 35 degrees each way. Because that limit is a piece of plastic and not a number in the code, the tightest turn the car can make never changes, and the driving code can count on it.

**Why 100 RPM.** People ask about this one, so here is the reasoning. The HuskyLens gives us about 20 frames a second. At 2 m/s the car would move 10 cm between one frame and the next, which means every decision about an obstacle is based on a picture of where things were 10 cm ago. Slowing the car down until it matches the camera is easier and more reliable than trying to speed the camera up. At 100 RPM on 65 mm wheels the top speed works out to 0.34 m/s, with lots of pulling power at the low end.

---

## Power System

The car runs on three lithium ion cells in series, which is about 11.1 V normally and 12.6 V when fully charged. The power splits right after a master fuse and a kill switch into three branches that never share a wire.

```mermaid
flowchart LR
    BAT[3S 18650 pack<br/>12.6V full] --> FUSE[Master fuse<br/>+ kill switch]

    FUSE -->|raw 12.6V| L298[L298N driver]
    L298 --> MOT[2x 100 RPM motors]

    FUSE -->|buck to 6.0V| SRV[MG996R servo]
    FUSE -->|buck to 5.0V| ESP[ESP32]
    FUSE -->|buck to 5.0V| HL[HuskyLens]
```

**Why three branches.** The motors want the full battery voltage and pull a lot of current when they speed up. The servo briefly pulls over 1.5 A if it pushes against a wall and gets stuck. If either of those shared a wire with the electronics, the voltage would dip enough to reset the ESP32 in the middle of a run. The annoying part is that this looks exactly like a software bug when you are trying to find it.

**Something worth knowing if you rebuild this:** the HuskyLens pulls around 320 mA while it is working. That is more than you want to run through the ESP32's own 5 V pin, so we feed it straight from the regulated supply instead.

**Low battery protection.** A 100k / 22k voltage divider feeds the battery voltage into one of the ESP32's analog pins. Lithium ion cells get damaged below about 9.0 V, so the code watches for 9.5 V and cuts the motors before it gets that far. This protects the battery. It is not a safety feature, and the fuse and the kill switch are what keep people safe.

---

## Sensor Integration

```mermaid
flowchart LR
    UL[Left ultrasonic] --> ESP[ESP32]
    UF[Front ultrasonic] --> ESP
    UR[Right ultrasonic] --> ESP

    HL[HuskyLens] -->|I2C, block coords| ESP
    IMU[MPU-6050] -->|I2C| ESP
    ESP -->|I2C| PCA[PCA9685] --> SRV[Steering servo]
    ESP --> L298[L298N] --> MOT[Drive motors]
```

**HuskyLens.** It sits on a printed bracket on the front bumper, tilted down so it can see both the far wall and the bottom of the nearest pillar. It joins the I2C bus alongside the PCA9685 and the IMU.

**Ultrasonics.** One at the front and one on each side. They give the lane centring code the numbers it needs, and just as importantly they measure the world in a completely different way from the camera. When the overhead lights glare off the mat and the camera cannot see, sound still works fine. We fire them one at a time so that one sensor never picks up another one's echo.

**IMU.** This tells us which way we are pointing, so that half a degree of steering error in each corner does not add up into the car driving crooked by the third lap.

**A wiring warning.** The ECHO pins on the HC-SR04 put out 5 V, and the ESP32's pins can only take 3.3 V. Every ECHO line goes through a 1k / 2k voltage divider. If you skip this you will damage the board.

### Pin map

| Function | ESP32 pin |
| --- | --- |
| I2C SDA / SCL for HuskyLens, PCA9685, MPU-6050 | GPIO 21 / 22 |
| Motor control | GPIO 25 / 26 / 27 |
| US left TRIG / ECHO | GPIO 5 / 18 |
| US front TRIG / ECHO | GPIO 4 / 19 |
| US right TRIG / ECHO | GPIO 17 / 16 |
| Battery sensing | Analog pin, through a 100k / 22k divider |

Everything shares one common ground.

---

## Software

### Development Environment

| Part | Language | Written and flashed with |
| --- | --- | --- |
| ESP32 | C++ / Arduino | Arduino IDE 2.0 or newer, with the ESP32 board package by Espressif |

The board is set up as an **ESP32 Dev Module**, with the serial monitor at 115200.

### Libraries and Dependencies

| Library | Why it is needed |
| --- | --- |
| `HUSKYLENS` | Talks to the camera over I2C and turns what comes back into something we can use. |
| `Adafruit_PWMServoDriver` | Drives the PCA9685. |
| `Wire` | I2C. Already comes with the Arduino IDE. |

### How the Code Works

Everything runs on the ESP32 as a state machine, so at any moment there is exactly one answer to the question of what the car is currently trying to do.

| State | What happens |
| --- | --- |
| `STATE_INIT` | Scans the I2C bus, checks the HuskyLens is there and in the right mode, checks the battery. |
| `STATE_WAIT` | Ready to go but sitting still, waiting for the start button. |
| `STATE_LANE_FOLLOW` | The normal state. A PID loop on the left and right wall distances keeps the car in the middle. |
| `STATE_AVOID_GREEN` | A green pillar has got close enough. Steers around it on the correct side and ignores lane following while it does. |
| `STATE_AVOID_RED` | The same thing, but steering the other way to pass on the opposite side. |
| `STATE_RECOVERY` | A wall closer than 10 cm, or the HuskyLens has stopped answering. Stops, backs up a little, straightens the wheels. |

```mermaid
flowchart TD
    A([Power on]) --> B[I2C scan, HuskyLens check,<br/>battery check]
    B --> C{Start button pressed?}
    C -->|No| C
    C -->|Yes| D[Read ultrasonics, IMU<br/>and HuskyLens blocks]

    D --> E{Wall under 10 cm<br/>or HuskyLens silent?}
    E -->|Yes| F[Stop, reverse, straighten]
    F --> D

    E -->|No| G{Pillar close<br/>enough to matter?}
    G -->|Red| H[Steer to pass on one side]
    G -->|Green| I[Steer to pass on the other]
    G -->|No| J[PID lane centring<br/>on wall distances]

    H --> D
    I --> D
    J --> D
```

**Staying in the middle.** When there is no pillar in sight, the car goes back to using the walls:

```
Error  = Distance_Left_Wall - Distance_Right_Wall
Output = Kp*Error + Ki*Integral(Error) + Kd*Derivative(Error)
```

`Kp` decides how hard the car pulls back toward the middle. `Kd` smooths that out and stops it wobbling side to side on the straights. `Ki` is kept very small, because a 90 degree corner creates a big error that lasts a while, and a large `Ki` would build that up and make the car overshoot on the way out of the turn.

### Seeing the Pillars

We teach the HuskyLens red as ID 1 and green as ID 2, using its Colour Recognition mode. It saves these in its own memory, so they stay there after the power is turned off and we do not have to teach it again every time.

Each frame it sends back the biggest matching patch of colour as a block, which is five numbers: an ID, a centre X, a centre Y, a width and a height. The ESP32 gets two useful things out of that. Comparing the centre X to the middle of the frame, which is 160 on a 320 pixel wide image, tells us which side the pillar is on. The size of the block tells us roughly how far away it is, since a pillar that takes up more of the picture must be closer. The colour decides which way we go and the size decides how hard we turn.

Because the camera does the recognising itself, it works on hue rather than raw RGB, which holds up much better when the lighting at the venue is not the lighting we practised in.

### Failure Handling

Most of what went wrong in testing was not the car making a bad decision. It was the car making a decision based on information that was no longer true.

- **The camera stops answering.** The ESP32 expects a reply from the HuskyLens at least every 100 ms. If nothing comes back it first tries to reset the I2C bus, and if that does not work it goes into `STATE_RECOVERY` instead of steering off an old pillar position.
- **Ultrasonic sound bouncing away.** If sound hits a wall at a sharp angle it never comes back, and the sensor just times out. The code checks the left and right readings against the track width it knows about, and if the total does not make sense it throws that reading away and holds the last good steering angle for three cycles.
- **Lighting changes.** Arena lighting washes the colours out. We deal with this two ways: a printed sun visor over the lens to block glare from above, and re-teaching the colours once we get to the venue.

### Getting the Code Running

1. Clone the repo and open the sketch in [`src/`](src/).
2. On the HuskyLens, go into its settings menu and set the protocol to **I2C**.
3. Put it in **Colour Recognition** mode. Point it at the red pillar and learn it as ID 1, then the green pillar as ID 2. Do this under the lighting you are actually going to run in.
4. Pick **ESP32 Dev Module** as the board, choose your serial port, and upload.
5. Open the serial monitor at 115200 and check the I2C scan finds all three devices.
6. Put the car up on blocks with the wheels off the ground. Check the motors spin the right way and the steering is centred before it ever touches the floor.
7. Press the start button.

### Tuning and Testing

The test sketches live next to the main code, because trying to debug a full program when you are not even sure the hardware works is a wasted afternoon.

- **I2C scanner** checks that the HuskyLens, PCA9685 and MPU-6050 are all responding before you try anything else. Most first day problems turn out to be a device that never showed up on the bus at all.
- **Servo sweep and motor test** runs the steering through its full range and spins the motors both ways, so a wiring mistake shows up in seconds instead of during a run.
- **HuskyLens block printer** prints the ID, centre X and size of every block to the serial monitor. This is how we set the size threshold, by walking a pillar toward the parked car and watching where the numbers cross over.

**What to tune, in this order:**

1. **Colour IDs.** Teach them again at the venue, every time. This is the number one reason pillars get missed.
2. **Size threshold.** This decides how close a pillar has to get before the car commits to going around it. Set it too low and the car swerves at pillars it has not even reached yet.
3. **PID values.** Start with `Ki` at zero. Turn `Kp` up until the car holds the middle, then add `Kd` until it stops wobbling on the straights, and only then add a tiny bit of `Ki` if it keeps settling off to one side.
4. **Steering centre.** Check the servo horn is at a true 90 degrees with the linkage taken off, before you bolt it back together.

---

## Safety

A 3S lithium battery holds enough energy to start a fire, and the steering has enough force to pinch a finger. These are the rules we work to.

- The pack is charged on a balance charger, on a surface that will not burn, never left alone and never inside a closed box.
- A master fuse sits on the positive wire from the battery, so a short further down blows the fuse instead of pushing the battery's full current through the wiring. The kill switch cuts every branch and can be reached from outside the chassis.
- The battery gets unplugged before any rewiring, and metal tools stay away from the battery terminals.
- Buck converters get checked with a multimeter before any board is plugged into them. One set wrong will kill the ESP32 and the HuskyLens instantly.
- Keep fingers away from the steering while the car is powered. The MG996R can jump without warning if the ESP32 resets.
- All motor code gets tested with the car up on blocks and the wheels off the ground.

The full list is in section 2.5 of the engineering documentation in [`docs/`](docs/).

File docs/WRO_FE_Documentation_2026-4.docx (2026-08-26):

# WRO Future Engineers 2026

Category: Future Engineers

## Table of Contents

1. Executive Summary & Vehicle Overview
2. Strategic Challenge Analysis
3. Criterion 1: Mobility & Mechanical Design
4. Criterion 2: Power & Sensor Architecture
5. Criterion 3: Software Architecture & Obstacle Strategy
6. Criterion 4: Systems Thinking & Engineering
7. Criterion 5: Reproducibility & GitHub Quality
8. Comprehensive Testing Logs & Analytics

## Executive Summary & Vehicle Overview

Yo_Bot_To_The_Future is our entry for the WRO 2026 Future Engineers competition: a 1/10 scale self-driving car built for both rounds. The whole vehicle runs on a single ESP32, which reads the sensors, decides what to do and drives the motor and steering itself. The camera it works with, a HuskyLens, has its own processor and does its own recognition, handing the ESP32 finished answers instead of pictures. That is the decision the rest of the design follows from.

System Parameter | Detailed Specification
Chassis | Optimized for balance between weight and strength, featuring a second layer to separate the electronic components that build this device.
Steering | The Ackermann trapezoidal linkage is driven by an analog servo which turns up to 35 degrees on either side.
Wheels | 65mm rubber tread wheels. Four in total, with the rear pair driven together.
Vision Processor | HuskyLens AI camera. It recognises the coloured pillars using its own onboard processor and reports back only where they are.
Main Controller | ESP32. The only controller on the vehicle. Everything the car does is decided here.
Sensor Input | A BNO055 IMU for direction, three HC-SR04 ultrasonic sensors for the walls, and the HuskyLens for the pillars.
Power Reservoir | Custom-made 3S 18650 lithium-ion pack, mounted on the roof tier along with the toggle switch and the start button.

Team Picture:

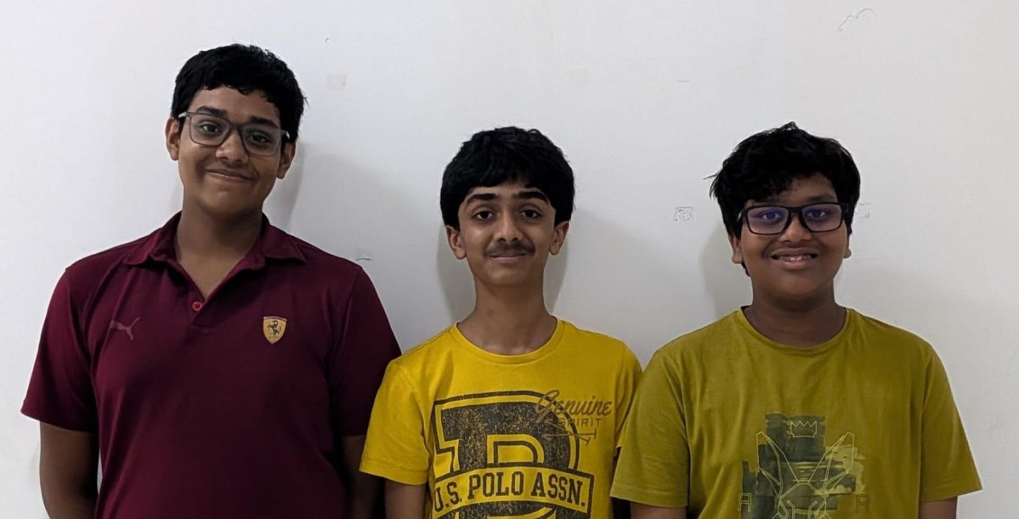
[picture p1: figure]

## Strategic Challenge Analysis

WRO Future Engineers 2026 asks for a 1/10 scale autonomous car that can drive a randomly generated walled track and choose its path based on coloured pillars. The judging favours teams who can show real automotive engineering, Ackermann steering in particular.

Our strategy was built upon fundamental pillars of autonomous vehicle design:

- Deterministic Actuation: when the software asks for a steering angle, the wheels have to end up in the same place every time. If the same instruction gives a slightly different result on each run, no amount of clever code will make up for it, because the code has no way of knowing what actually happened. This is what pushed us towards Ackermann steering, where the geometry decides the outcome rather than friction.
- Data Isolation: working out what is in a picture is slow, and holding a steering servo steady is a job that cannot wait. Ask one processor to do both and the steering stutters every time the picture takes longer than usual. We kept the two jobs on separate hardware. The camera works on the picture and sends back a short answer, and the ESP32 spends its time on the parts that have to happen on schedule.

## 1. Mobility & Mechanical Design

### 1.1 Chassis Engineering & Material Selection

The chassis is the backbone of the car and everything else is bolted to it, so it was the first thing we got right. A chassis with flex in it does not stay still while the car is driving, and because the camera is mounted to it, the camera moves too. The camera judges distance from how big a pillar looks, so a camera that keeps shifting gives us answers that change for no reason. A stiff chassis is what makes the camera readings mean anything at all.

We designed the chassis in Onshape and 3D printed it. We chose PETG over the more common PLA because it takes an impact without shattering and holds its shape when it gets warm, both of which matter on a car that gets knocked into walls and sits beside a motor driver that heats up. The parts use a honeycomb infill, which gets most of the stiffness of a solid part for a fraction of the plastic. Printing it ourselves also meant that when a mounting point turned out to be wrong, we changed the file and printed it again.

### 1.2 The Roof Tier Module: Iterative Evolution

Our first prototype put everything on one flat plate, which caused two problems. The motor driver gets hot after the motor has run a while, and crowded onto one level that heat has nowhere to go. The wiring shared the same space too, so battery leads ran alongside sensor wires, which is a good way to get sensor readings that are wrong for no visible reason.

The Solution: We designed a secondary roof tier that bolts onto the chassis walls. The roof tier carries the battery pack, the toggle switch and the start button, and their wiring drops down to the lower deck through a single hole in the plate. Splitting the car across two levels gave us three things at once:

1. Power and signal kept apart: the battery wiring now runs on its own level, well away from the sensor wiring below. A motor pulling current throws out electrical interference, and keeping that away from the wires carrying sensor readings means fewer readings that come back wrong for no visible reason.
2. Cooling: with the roof lifted clear on standoffs, the lower deck is open on every side and air moves through it while the car drives. Heat from the motor driver gets carried away instead of building up around the electronics.
3. Weight where we want it: lifting the battery higher is normally a bad idea, because weight up high makes any vehicle less stable. We accepted that because of where we put it. The battery is the heaviest single item on the car, and sitting it above the rear axle presses the driven wheels into the ground. More weight on the driven wheels means they grip instead of spinning, and that matters every time the car pulls away.

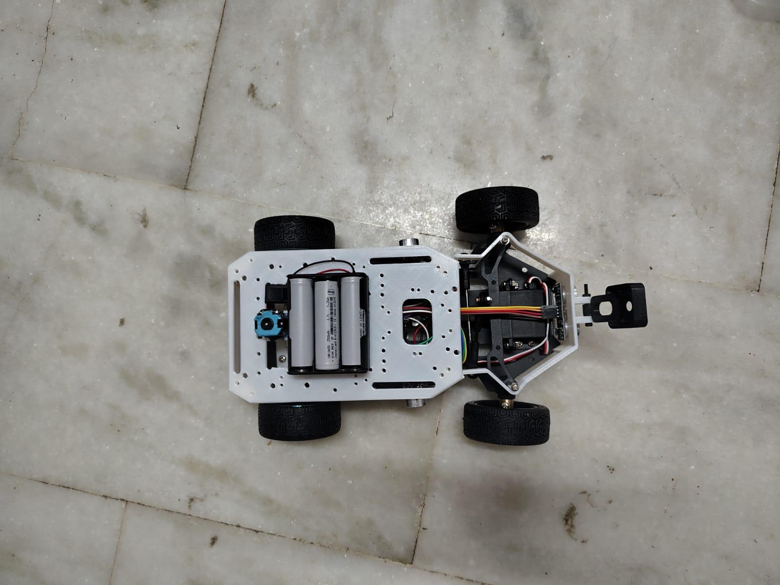
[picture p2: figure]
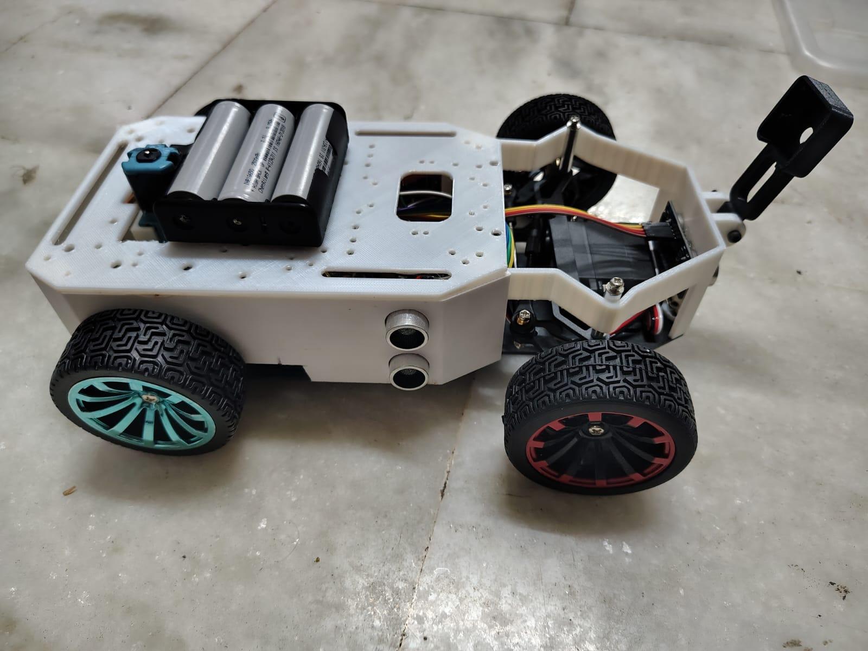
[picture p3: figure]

### 1.3 Ackermann Steering Geometry & Kinematics

In an effort to conform to the Future Engineers category rules, our car employs true steered front axle design. We chose not to use the differential or skid steering method. With the skid steering system, the wheels have to scrub against the surface to make the car turn. These forces introduce non-linear friction coefficients which nullify the accuracy of odometry measurements and make open-loop steering impossible.

Our car uses a trapezoidal Ackermann linkage, the same arrangement used on a real car. Going around a corner, the two front wheels are not travelling on the same circle: the inside wheel follows a tighter path, so it has further to turn. Turn both by the same amount and only one can point the right way, leaving the other to drag sideways for the whole corner. Ackermann angles the steering arms inwards so the inside wheel turns a little further, and both wheels roll around the same centre point.

We also built physical stops into the chassis to limit how far the steering can travel, deliberately as a piece of plastic rather than a limit in code. Software can be flashed with the wrong value, and a servo told to reach somewhere the linkage cannot will keep pushing until it strips its own gears. A physical stop protects the linkage whatever the code does, and it makes the tightest turn a fixed, known quantity the driving code can rely on.

### 1.4 Drivetrain, Propulsion, & Torque Analytics

The propulsion system is split into two separate jobs. At the front, a single servo steers the wheels through the Ackermann linkage. At the rear, one hobby gear motor drives both rear wheels through a shared axle, controlled by an L298N H-Bridge controller. Keeping drive and steering apart means neither one has to compromise for the other, and the speed we run the motor at is not an arbitrary choice.

The car is deliberately not fast, and that is the part people question most. Every sensor takes time to produce an answer, and the car keeps moving while it waits, so by the time an answer arrives it describes where things were a moment ago. The faster the car drives, the bigger that gap gets. A car that reacts to where a wall used to be will hit it, so we slowed the car down to match the speed its sensors can actually think at.

With a wheel diameter of 65 mm, we have a wheel circumference of 204.2 mm. The gearing also works in our favour at low speed. A geared motor trades away top speed for pulling power, which is exactly the right trade here, because the car spends its time starting, stopping and reversing out of corners rather than going flat out down a straight.

## 2. Power & Sensor Architecture

### 2.1 Power Tree, Isolation, & Load Balancing

The electrical design is built around one idea: keep the parts that draw big, sudden bursts of current away from the parts that need a steady supply. The car runs on a pack we built ourselves from three 18650 lithium ion cells in series, giving roughly 12.6 volts fully charged and around 11.1 for most of a run. It sits on the roof tier, and the cells are removable so a flat pack can be swapped for a fresh one between runs rather than charged on the car.

The power tree splits immediately after the toggle switch on the roof tier:

- Branch 1, the motor: full battery voltage goes straight to the motor driver with nothing in the way. The motor is by far the hungriest thing on the car, especially in the moment it starts moving, and putting anything in between would only get in the way.
- Branch 2, the steering: a buck converter steps the battery down to a lower, steady voltage, and that supply feeds the steering and nothing else. Servos are unpredictable customers. Most of the time they draw very little, but the instant one is pushed against something it cannot move, it draws a large amount without warning. Giving it its own supply means that when this happens, it happens somewhere that does not matter.
- Branch 3, the electronics: a second buck converter provides a clean, steady 5 volts for the ESP32, the HuskyLens and the rest of the electronics. This branch is the reason the other two are kept separate. If the voltage here dips even briefly the ESP32 restarts, and a controller that restarts mid run does not pause, it forgets everything and begins again. Worse, it looks exactly like a bug in the code when you are hunting for it.

### 2.2 Li-ion Battery Discharge Characteristics

Lithium ion cells are permanently damaged if drained too far, and a cell run flat never holds as much charge again. A pair of resistors divides the pack voltage down to a level the ESP32 can measure, and it watches this throughout the run, cutting power to the motor below a safe threshold. We would rather stop a run early than replace the pack. This protects the battery; it is not a safety feature and does not replace the toggle switch.

### 2.3 Sensor Topology: Vision vs. Proximity

Direction, the BNO055 IMU: this is the sensor the car steers by. An IMU measures how the vehicle is oriented, and the BNO055 does its own processing internally, so we can ask it directly which way the car is facing. Instead of reacting to whichever wall happens to be nearer, the car picks a direction and holds it, so one odd reading never drags it off course.

Distance, three HC-SR04 ultrasonics: one faces forward and one sits on each side, sending out a pulse of sound and timing how long it takes to come back. The forward sensor tells us when a wall is close enough to turn at, and the side sensors tell us which way the track opens up. We fire them one at a time so no sensor mistakes another's echo for its own. Using sensors that work in different ways is deliberate: light and sound fail in different situations, so when a reflection off the mat blinds the camera, the ultrasonics keep working.

### 2.4 Comprehensive Pinout & Wiring Manifesto

Robotic reliability is 90% wiring. Each and every wire on this robot is crimped, strain-relieved, and tagged.

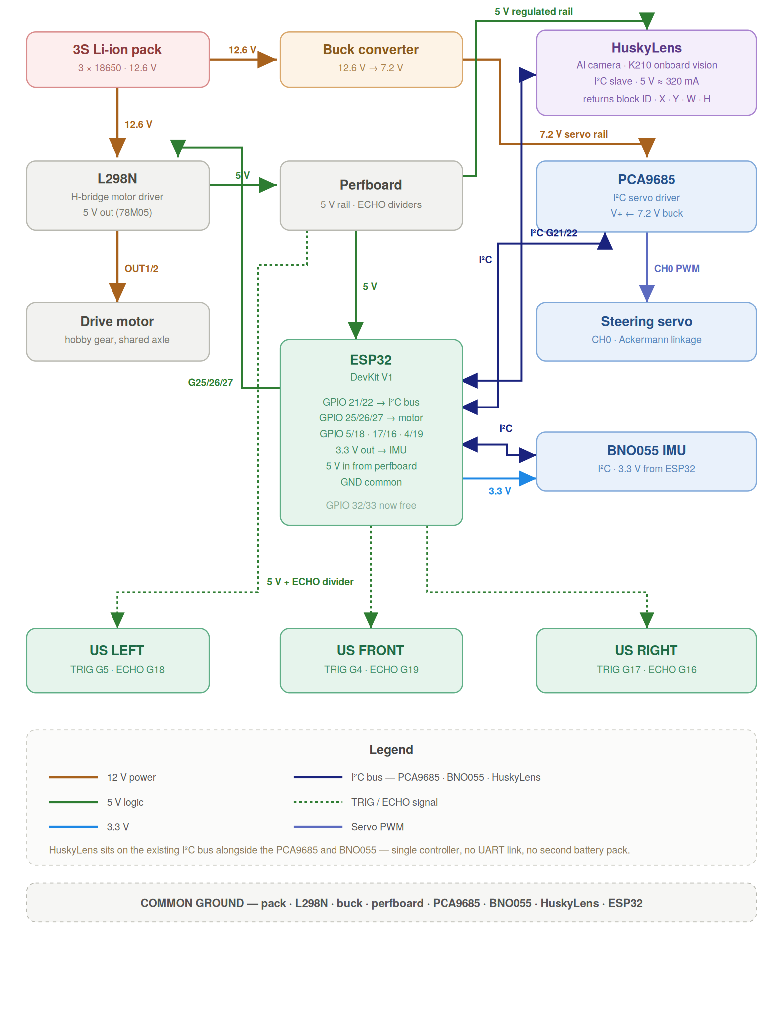
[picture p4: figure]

### 2.5 Safety Precautions

A lithium battery pack holds enough energy to start a fire, and the steering has enough force to pinch a finger. Both are far easier to avoid than to deal with afterwards. These are the rules we work to every time we build, test or compete with this vehicle.

Battery handling

- Cells: the pack is not charged on the vehicle. The 18650 cells are removable, so a flat pack gets swapped for a charged one between runs. Any charging happens away from the car, on a surface that will not burn, never unattended and never inside a closed box. Being able to lift the pack straight off the roof tier is part of why it is mounted there.
- Damaged cells: any cell that swells, is punctured or dented, or feels unusually warm is retired immediately. A damaged lithium cell does not get better and gives little warning before it fails.
- Storage: if the pack is going to sit unused for a while, we leave it part charged rather than full or empty. Both extremes shorten its life.

Electrical safety

- Cutting the power: the toggle switch on the roof tier cuts power to everything on the car, and it sits on top where it can be reached from outside the chassis while the car is moving. It is the first thing any of us goes for if a run starts going wrong.
- Working on the car: the battery is unplugged before any rewiring or component swap, and metal tools stay away from the terminals. Dropping a screwdriver across them is the easiest way to short this vehicle.
- Before powering up: the buck converters are checked with a multimeter before any board is connected, and every exposed joint is covered so no bare wire can touch the chassis once the car vibrates.

Mechanical and operating safety

- Steering: fingers stay clear of the steering linkage whenever the car is powered. The servo has enough torque to pinch and can move without warning if the controller resets.
- Testing: all motor code is tested with the car on blocks and the wheels off the ground. Only once the motor turns the right way and the steering is centred does it go on the floor.
- Starting a run: the car never starts itself when power is applied. We flip the toggle switch, wait a few seconds for the sensors to come up, then press the button. Before every run we check the switch is reachable, the battery and camera bracket are secure, and no loose wire sits near the drivetrain.
- During a run: one of us stays within reach of the switch for the whole run. Everyone else stays outside the track boundary.

## 3. Software Architecture & Obstacle Strategy

### 3.1 Vision Offloading: Smart Sensor & Real-Time Controller

There are normally two ways to add a camera to a robot and both cause problems. A small microcontroller cannot handle a video feed at all. A full computer can, but it runs an operating system that decides for itself what to do and when, so the timing our steering depends on is no longer ours. We avoided both by moving the vision work into the camera.

The HuskyLens does the recognising itself, using its own processor and built-in software. This is not OpenCV and not code we wrote. We never see the pixels and cannot change how they are handled, and we accepted that on purpose: in exchange, an answer arrives in the same amount of time on every frame.

That leaves the ESP32 with a much simpler job. It runs one compiled C++ program and deals only with the present moment: which way the car is pointing, how far the wall is, where the last pillar was reported, and what the steering and motor should be doing about it. It never has to stop and think about a picture, which is why a controller this small is enough.

### 3.2 Vision Pipeline & Colour Recognition

The HuskyLens is used in its Colour Recognition mode. Before a run we show it each pillar and tell it to remember that colour, and it stores this in its own memory so it survives a power cycle. We always teach the colours again at the venue, under the lights we will actually run under, because arena lighting is never the same as our workshop and this is the most common reason a pillar gets missed.

1. Learning: the red pillar is taught as ID 1 and the green pillar as ID 2. Which ID belongs to which colour is what the code checks against, so getting these the right way round matters.
2. Block extraction: on every frame the camera finds the largest patch of a colour it recognises and describes it as a block, telling us which colour it is, where the middle of it sits in the frame, and how big it is.
3. Working out what to do: the ESP32 gets two useful things from that. Where the block sits relative to the middle of the frame tells it which side the pillar is on, and how big the block is tells it roughly how close the pillar is, because something nearer fills more of the picture. The colour decides which way to go around it and the size decides when to commit.

### 3.3 State Machine Topology & Transitions

We wrote two separate programs, one per round, rather than one that handles both. The open round never needs to see a pillar, so vision code there would only add ways to go wrong. Both share the same wiring, so nothing on the car changes between rounds.

Both work as a state machine, meaning that at any moment there is exactly one answer to what the car is trying to do. That makes its behaviour predictable and makes it possible to work out afterwards why it did something.

- Starting up: the car checks that every sensor is responding and that the battery is charged before it will do anything at all. We would far rather find out something is not answering while the car is sitting still than halfway down the track.
- Waiting: the car is powered and ready but deliberately stationary, waiting for the button to be pressed. It never begins moving on its own when power is applied.
- Driving: the normal state. The car holds its heading using the IMU and watches the forward ultrasonic sensor for a wall coming up.
- Cornering: once the wall ahead is close enough, the side sensors decide which way the track turns and the car makes the turn. Normal steering is suspended while this happens, because during a deliberate turn the car is supposed to be pointing away from its target direction.
- Avoiding a pillar, obstacle round only: when the camera reports a pillar close enough to matter, the car steers to one side to go around it and hands control back once it is past. Which side it goes depends on the colour.
- Recovering: if the car finds itself far too close to a wall, or a sensor stops replying, it stops, reverses a short distance and straightens up before trying again. Trying to steer out of a corner you are already wedged into usually just wedges you in harder.

### 3.4 Control Theory: Holding a Straight Line

Driving in a straight line is harder than it sounds. Nothing on a small vehicle is perfectly symmetrical, so a car told simply to go forwards will always drift to one side. We steer by direction rather than by distance from the walls: the IMU tells us which way the car is actually pointing, we compare that to the direction we want, and the difference drives the steering. The correction is capped so no single strange reading can throw the wheels hard over, and very small errors are ignored so the car does not twitch constantly. We tuned it by hand on the track.

## 4. Systems Thinking & Engineering Decisions

### 4.1 Trade-off Matrices & Critical Constraints

Every decision in this vehicle involved an engineering trade-off. We documented our decision logic to demonstrate advanced systems thinking:

Design Choice | Chosen Solution | Rejected Alternative | Systems Logic & Trade-off Accepted
Steering | Ackermann Linkage | Differential/Skid Steer | Accepted mechanical complexity for the immense benefit of deterministic, repeatable cornering.
Motor Speed | Single geared drive motor | High-speed direct drive | Traded maximum top speed for reliability. Slower robot which processes 100% of the camera frames accurately is better than a faster robot which fails in its processing and crashes.
Vision | HuskyLens smart camera | Raw camera module plus a separate computer running an OpenCV pipeline we would write ourselves | Sacrificed fine-grained control over the image pipeline for a fixed, deterministic frame rate, far lower power draw, no boot time, and no operating system scheduler competing with our PWM timing.
Chassis | Multi-Tier with Roof | Single Flat Plate | Raised center of mass slightly, but fixed thermal and wiring congestion problems completely.

### 4.2 Failure Mode and Effects Analysis

- A wall reading that makes no sense. Sound hitting a wall at a sharp angle bounces away instead of coming back, so the sensor reports nothing. Because the car steers by direction rather than by wall distance, one bad reading does not move the steering at all. It only affects when the car decides to turn, and the code confirms a reading before acting on it.
- A sensor stops answering. A wire works loose or the data connection locks up. Mitigation: the ESP32 expects a reply from each sensor regularly, and if one goes quiet it first tries to reset the connection. If that does not work, the car stops rather than carrying on using information it knows is out of date.
- Lighting we did not practise in. Venue lighting washes out the colours and the camera stops recognising pillars it had no trouble with at home. Mitigation: a printed visor over the lens to cut glare from overhead lights, and teaching the colours again on site every time.

## 5. Criterion 5: Reproducibility & GitHub Quality

### 5.1 Open Source Commitment & Repo Structure

Our entire project is open-source and highly structured, ensuring that any team worldwide can reproduce our vehicle.

### 5.2 Master Bill of Materials (BOM)

- 1x ESP32 WROOM-32 DevKit V1 microcontroller
- 1x HuskyLens AI vision sensor
- 1x L298N dual H-bridge motor driver
- 1x Hobby Gear DC Motor driving both rear wheels through a shared axle
- 1x MG996R metal gear steering servo
- 1x BNO055 IMU
- 1x PCA9685 servo driver
- 3x HC-SR04 ultrasonic sensors
- 2x LM2596 buck converters
- 1x custom 3S 18650 lithium ion battery pack with BMS
- 4x 65mm rubber tread wheels
- PETG filament for the printed chassis and roof tier
- 1x toggle switch and 1x pushbutton, both mounted on the roof tier
- Misc: 50mm M3 standoffs, M3x8mm screws, jumper wires, perfboard, resistors for the voltage dividers

### 5.3 Step-by-Step Mechanical Assembly Guide

1. Print the chassis: slice the base plate and the roof tier in PETG with a honeycomb infill.
2. Drivetrain Installation: Mount the hobby gear motor to the rear mounting bracket using M3x8mm screws. Fit the shared rear axle, then slide the 65mm rear wheels onto it and secure the set screws.
3. Steering: fit the kingpins into the front steering knuckles and attach the tie-rod linkage. Mount the servo in the central chassis slot. Centre the servo horn before attaching the linkage, because attaching it off-centre leaves the car permanently crooked. Check the hard stops by hand with the servo unpowered.
4. Roof tier: screw the four 50mm M3 standoffs into the base plate and mount the roof tier on top. The battery pack, toggle switch and pushbutton all go up here, wiring dropping through the hole in the plate to the deck below.
5. Lower deck: secure the ESP32, the L298N motor driver and the servo driver to the base plate, keeping the sensor wiring away from the motor leads. Bolt the HuskyLens into the front bumper mount using its supplied bracket, angled slightly downward so it sees both the far wall and the bottom of the nearest pillar.

### 5.4 Step-by-Step Electrical Assembly Guide

1. Power distribution: run the positive lead from the battery to the toggle switch on the roof tier, then down through the hole in the plate. From there it splits to the motor driver and to both buck converters.
2. Buck calibration: do this before anything else is plugged in. Set each converter to its correct voltage with a multimeter. One left at the wrong setting will destroy every board downstream the moment power is applied.
3. Voltage dividers: the ultrasonic sensors reply at 5 volts and the ESP32's pins can only take 3.3, so every one of those lines goes through a pair of resistors that divides the voltage down first. Skipping this will damage the ESP32. A further divider brings the battery voltage into range.
4. Data lines: set the HuskyLens to I2C in its own settings menu, then wire it onto the shared I2C bus alongside the IMU and the servo driver. Finally, make sure every component shares one common ground. Boards that do not share a ground behave in ways that make no sense and take a long time to diagnose.

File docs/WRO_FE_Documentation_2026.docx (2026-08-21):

# WRO Future Engineers 2026

Category: Future Engineers

## Table of Contents

1. Executive Summary & Vehicle Overview
2. Strategic Challenge Analysis
3. Criterion 1: Mobility & Mechanical Design
4. Criterion 2: Power & Sensor Architecture
5. Criterion 3: Software Architecture & Obstacle Strategy
6. Criterion 4: Systems Thinking & Engineering
7. Criterion 5: Reproducibility & GitHub Quality
8. Comprehensive Testing Logs & Analytics

## Executive Summary & Vehicle Overview

Yo_Bot_To_The_Future robot is one that has high performance and is made for the sole aim of addressing the problems presented by the WRO 2026 Future Engineers competition. Through the utilization of a HuskyLens AI vision sensor paired with an ESP32 microcontroller that handles every real-time control task, we achieve seamless coordination between perception and movement without ever loading the control loop with image processing.

System Parameter | Detailed Specification
Chassis | Optimized for balance between weight and strength, featuring a second layer to separate the electronic components that build this device.
Steering | The Ackermann trapezoidal linkage is driven by an analog servo which turns up to 35 degrees on either side.
Wheels | High-traction rubber treads with a 65mm diameter, 204mm circumference and predictable change in position.
Vision Processor | HuskyLens AI camera with an onboard, performing all colour recognition internally.
Main Controller | ESP32, dedicated to real-time decisions, PWM signal generation, and I2C polling.
Sensor Input | HuskyLens in Colour Recognition mode for dynamic colour object detection, with HC-SR04 Ultrasonic sensors for avoiding wall collision.
Power Reservoir | Custom-made 3S 18650 lithium-ion battery pack, providing 11.1V normally.

Team Picture:


## Strategic Challenge Analysis

Requirements of WRO Future Engineers 2026 include the development of an autonomous car on 1/10 scale that is able to drive through a randomly created track surrounded by walls and determine its path based on colored pillars. The criteria of this competition favors the teams that will be able to prove their knowledge of automotive engineering (e.g., Ackerman system).

Our strategy was built upon fundamental pillars of autonomous vehicle design:

- Deterministic Actuation: The robot's physical response to a software command must be identical every single time. This put our team in favor of Ackermann steering.
- Data Isolation: Processing a live camera feed requires massive computational thinking. If the same processor handling the camera is also responsible for generating the precise PWM pulses for the steering servo, the servo will jitter due to thread blocking. Thus, the HuskyLens handles all the image data on its own processor and reports only coordinates, and the ESP32 handles the time-critical pulses.

## 1. Mobility & Mechanical Design

### 1.1 Chassis Engineering & Material Selection

The chassis is considered to be the backbone of the car itself. At an early stage in our design process, we found out that a flexible chassis will lead to an error in the pitch and angle of our HuskyLens, leading to large mathematical errors in our distance estimation system. Even when the camera tilts just two degrees downwards because of heavy acceleration, the system sees objects closer than they really are.

In order to remove this problem, the chassis was designed using Tinkercad software and then manufactured using 3D printing. We chose high density PETG filament for printing as it has better resistance to impact and glass transition temperature. The chassis has a honeycomb infill design which maximizes stiffness and maintains strength.

### 1.2 The Roof Tier Module: Iterative Evolution

In phase two of our prototype, there was one key issue identified in the design. This included electromagnetic interference and thermal saturation. The L298N H-Bridge dissipates a significant amount of heat under sustained motor load. When the logic boards sit directly beside it, that heat pools in one region of the deck. Another issue is that by putting all the wires on one layer, it became a rat's nest.

The Solution: We designed a secondary roof tier that bolts onto the chassis walls. This roof tier held the battery pack and the ESP32 microcontroller away from the lower deck. This design choice came with three benefits:

1. EMI Isolation: The sensitive logic-level I2C data lines on the roof are distanced from the noisy magnetic fields generated by the 100 RPM motors below.
2. Thermal Management: The lower deck became a wind tunnel, allowing air flow directly over the L298N heatsink.
3. Center of Mass Optimization: While raising the battery usually negatively impacts the CoM, placing it directly over the rear drive axle massively increased the normal force on the rear tires, practically eliminating wheel slip during aggressive acceleration.


### 1.3 Ackermann Steering Geometry & Kinematics

In an effort to conform to the Future Engineers category rules, our car employs true steered front axle design. We chose not to use the differential or skid steering method. With the skid steering system, the wheels have to scrub against the surface to make the car turn. These forces introduce non-linear friction coefficients which nullify the accuracy of odometry measurements and make open-loop steering impossible.

A trapezoidal Ackermann steering was used in the design of the car. On a turn, the inner wheel needs to follow a smaller radius circle compared to the outer wheel. When both wheels steer at the same angle, there is bound to be slip between them. It is by this geometry that the steering linkages need to be at an angle to make sure that their geometric lines meet at the rear axle.

To prevent mechanical binding and servo stall, we implemented physical hard stops on the chassis that restrict the maximum tie-rod horizontal travel, effectively capping our maximum steering angle at precisely 35 degrees left and right. This fixed maximum allows the path-planning algorithm to rely on a hardcoded minimum turning radius.

### 1.4 Drivetrain, Propulsion, & Torque Analytics

The propulsion system in the rear end is composed of two 100 RPM geared DC motors controlled by an L298N H-Bridge controller. The choice of 100 RPM motors is not an arbitrary choice.

Speed vs Frame Processing Latency: If we take into account the speed of the robot to be 2.0 m/s and that the HuskyLens reports recognised colour blocks at roughly 20 FPS. Then, the robot travels 10 cm for every frame data collected. Thus, the faster the motors are, the greater the distance traveled between frames and hence late collision detection and wall collision. With 100 RPM motors, we achieve perfect speed synchronization with the latency of the vision module.

With a wheel diameter of 65 mm, we have a wheel circumference of 204.2 mm. For 100 RPM, the theoretical top speed is 0.34 m/s with very high torque at low speeds.

## 2. Power & Sensor Architecture

### 2.1 Power Tree, Isolation, & Load Balancing

The electrical design system has been built on the basis of isolation and prevention of brown out conditions. The battery used for the power of the vehicle is a custom made 3S 18650 Lithium-Ion battery which provides 12.6 volts of power output with nominal voltage of 11.1 volts.

The power tree splits immediately after the master fuse and emergency kill switch:

- Branch 1 (High Power): The uncontrolled 12.6V feeds directly to the L298N H-Bridge motor driver. This provides the drive motors with access to immense burst currents in order to accelerate.
- Branch 2 (Servo Logic): The 12.6V is directed towards a highly efficient buck converter which drops the voltage to exactly 6.0V. The 6V rail powers the steering servo alone. During stall against a wall, the servo pulls more than 1.5Amps in the blink of an eye. With the help of this buck converter, this current spike does not go to the microcontroller.
- Branch 3 (Digital Logic): The second 5V step-down power converter powers the ESP32 microcontroller and the HuskyLens to provide a pure power supply without any ripple to prevent the controller from randomly rebooting during operation. The HuskyLens draws roughly 320mA while actively recognising, so it is fed from this regulated rail rather than from the ESP32's own 5V pin.

### 2.2 Li-ion Battery Discharge Characteristics

Lithium Ion is unstable when it is over-discharged. If the pack voltage is less than 9.0 volts, then there will be some chemical damage. We have designed an impedance voltage divider, which is connected to the ESP ADC directly. The ESP keeps monitoring the pack voltage. If it drops below 9.5 volts, then an interrupt signal is generated, and the H-bridge circuit stops working.

### 2.3 Sensor Topology: Vision vs. Proximity

Primary Vision (HuskyLens): The HuskyLens has been placed on a specially designed bracket fixed onto the front bumper, which has been calibrated to view the horizon of the field wall and base of the colored obstacle poles. The visual sense is used to keep the vehicle in its path and classify obstacles. Because the HuskyLens carries its own K210 vision processor, it returns only a small list of recognised block coordinates over I2C rather than a raw video stream, which is what allows a single microcontroller to run the whole vehicle.

Secondary Proximity (Ultrasonic): The ultrasonic sensors HC-SR04 were attached to the front and side wings of the chassis. These use an entirely different physical approach (sound waves compared to photons). In case the camera cannot see due to a bright overhead light (specular glare off the mat), the ultrasonic sensors serve as a fallback. We activate the sensors in a round robin fashion to avoid acoustic interference (the echo of one ping heard by the other sensor).

### 2.4 Comprehensive Pinout & Wiring Manifesto

Robotic reliability is 90% wiring. Each and every wire on this robot is crimped, strain-relieved, and tagged.

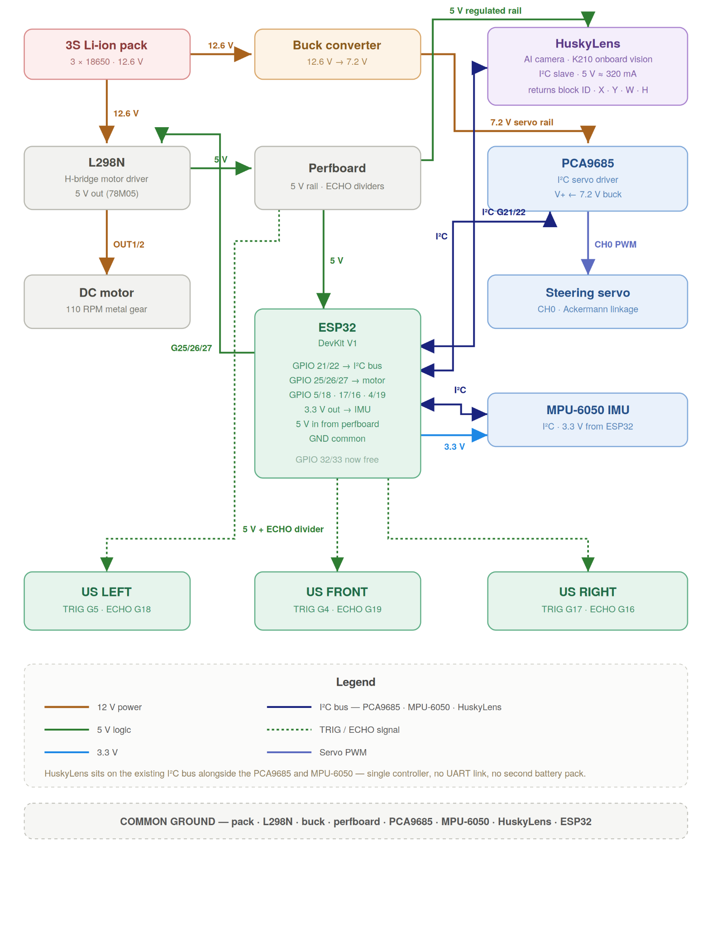
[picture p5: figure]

## 3. Software Architecture & Obstacle Strategy

### 3.1 Vision Offloading: Smart Sensor & Real-Time Controller

A general-purpose microcontroller does not have the capability to deal with raw video signals. A single-board computer running a full operating system, on the other hand, has issues with timing of the PWM signal because of the overhead of the OS scheduler. This problem is solved in our software architecture by pushing the vision workload into the sensor itself.

The HuskyLens is responsible for executing the recognition work. Its onboard K210 processor runs the colour recognition model, so the heavy per-pixel maths never touches our control loop.

The ESP32 handles the compiled C++ program. It is the brain stem of our project. It just deals with the current time frame and thinks only about the following questions: How many microseconds does my signal need to be right now? What is the current battery voltage? Where did the HuskyLens last report a coloured block?

### 3.2 Vision Pipeline & Colour Recognition

Our system for obstacle avoidance uses the HuskyLens in Colour Recognition mode. Colours are taught to the sensor during setup under arena-representative lighting, and the K210 performs its thresholding internally in a hue-based colour space, which is much more resilient to changes in ambient light conditions than raw RGB comparison.

1. Learning: Before a run, the red pillar is learned as ID 1 and the green pillar as ID 2. The learned models are stored in the HuskyLens's own flash memory, so they survive a power cycle.
2. Block Extraction: For every frame, the HuskyLens isolates the largest contiguous region matching a learned colour and returns a bounding block containing its ID, centre X, centre Y, width and height.
3. Spatial Mapping: The ESP32 finds the obstacle's position by checking where the centre of the returned block is compared to the centre of the camera frame (160 on a 320-pixel-wide frame). It also estimates how far away it is based on the size of the block. A bigger block means the obstacle is closer.

### 3.3 State Machine Topology & Transitions

The vehicle operates autonomously via a finite state machine, ensuring predictable behavior under all conditions:

- STATE_INIT: Hardware boot sequence, I2C bus scan, HuskyLens handshake and mode check, battery voltage check.
- STATE_WAIT: Vehicle is armed but stationary, polling the physical start button.
- STATE_LANE_FOLLOW: Default active state. Uses ultrasonic sensors and vision to maintain a central vector between the track walls.
- STATE_AVOID_GREEN: Triggered when a green block's area exceeds the threshold. Generates a steering vector to pass the obstacle on the designated correct side, overriding lane-following.
- STATE_AVOID_RED: Same logic as green, but generating an inverted steering vector to pass on the opposite side.
- STATE_RECOVERY: Triggered if front ultrasonic sensors detect an immediate wall (< 10cm) or if the HuskyLens stops responding on the I2C bus. The ESP32 autonomously halts the motors, reverses slightly, and straightens the steering to prevent a crash.

### 3.4 Control Theory: PID Controller for Lane Centering

When the camera does not see an obstacle, the robot defaults to following the walls using a Proportional-Integral-Derivative (PID) control loop based on the lateral ultrasonic sensors.

Error = (Distance_Left_Wall - Distance_Right_Wall) P_Out = Kp * Error I_Out = Ki * Integral(Error) D_Out = Kd * Derivative(Error) Steering_Angle = P_Out + I_Out + D_Out

We carefully adjusted these settings. Kp controls how strongly the robot turns back toward the center. Kd helps smooth out the turns and stops the robot from wobbling on straight paths. Ki is kept very low to avoid problems when the robot takes sharp 90° turns.

## 4. Systems Thinking & Engineering Decisions

### 4.1 Trade-off Matrices & Critical Constraints

Every decision in this vehicle involved an engineering trade-off. We documented our decision logic to demonstrate advanced systems thinking:

Design Choice | Chosen Solution | Rejected Alternative | Systems Logic & Trade-off Accepted
Steering | Ackermann Linkage | Differential/Skid Steer | Accepted mechanical complexity for the immense benefit of deterministic, repeatable cornering.
Motor Speed | 100 RPM Geared Motors | 300+ RPM High-Speed Motors | Traded maximum top speed for reliability. Slower robot which processes 100% of the camera frames accurately is better than a faster robot which fails in its processing and crashes.
Vision | HuskyLens smart camera | Raw camera module + on-board computer running OpenCV | Sacrificed fine-grained control over the image pipeline for a fixed, deterministic frame rate, far lower power draw, no boot time, and no operating system scheduler competing with our PWM timing.
Chassis | Multi-Tier with Roof | Single Flat Plate | Raised center of mass slightly, but fixed thermal and wiring congestion problems completely.

### 4.2 Failure Mode and Effects Analysis

- Failure Mode 1: Ultrasonic Specular Reflection. Sound waves bouncing off walls at extreme angles never return to the sensor, causing a timeout. Mitigation: The software checks the sum of (Left_Distance + Right_Distance). If the sum drastically exceeds the known track width, the software flags the data as invalid and holds the last known good steering angle for 3 frames.
- Failure Mode 2: I2C Bus Dropout. A loose wire or a bus lock-up disconnects the HuskyLens from the ESP32. Mitigation: The ESP32 expects a valid response from the HuskyLens at least every 100ms. If the request times out, the ESP32 first attempts an automatic bus recovery, and if that fails it auto-triggers the STATE_RECOVERY brake protocol.
- Failure Mode 3: Variable Lighting Conditions. Competition arena lighting washes out the red/green boxes. Mitigation: Re-teaching the colour IDs on-site under the actual arena lighting, and installing a physical 3D-printed sun-visor over the HuskyLens lens to reduce overhead glare.

## 5. Criterion 5: Reproducibility & GitHub Quality

### 5.1 Open Source Commitment & Repo Structure

Our entire project is open-source and highly structured, ensuring that any team worldwide can reproduce our vehicle.

### 5.2 Master Bill of Materials (BOM)

- 1x ESP32 WROOM-32 DevKit V1 Microcontroller
- 1x HuskyLens AI Vision Sensor
- 1x L298N Dual H-Bridge Motor Driver
- 2x 12V 100 RPM Geared DC Motors with hall-effect encoders (encoders currently unused, reserved for future odometry upgrades)
- 1x MG996R High-Torque Metal Gear Servo
- 3x HC-SR04 Ultrasonic Sensors
- 2x LM2596 DC-DC Buck Converters
- 1x Custom 3S1P 18650 Li-Ion Battery Pack (with 10A BMS)
- 4x 65mm Rubber Tread Wheels
- 1x Roll of PETG Filament (for custom 3D printed chassis and roof)
- Misc: M3 standoffs, jumper wires, perfboard, resistors (100k, 22k, 1k, 2k for voltage dividers)

### 5.3 Step-by-Step Mechanical Assembly Guide

1. Print the Chassis: Slice the base plate and roof tier design using PETG with 30% infill for maximum structural rigidity.
2. Drivetrain Installation: Mount the two motors to the rear mounting brackets using screws. Slide the 65mm rear wheels onto the D-shafts and secure the set screws.
3. Steering Assembly: Insert the kingpins into the front steering knuckles. Attach the trapezoidal tie-rod linkage. Mount the servo to the central chassis slot, ensuring the servo horn is perfectly centered at 90 degrees before attaching the linkage wire. Verify the 35-degree hard stops manually.
4. Roof Tier Integration: Screw four 50mm M3 brass standoffs into the base plate. Mount the roof tier on top.
5. Component Placement: Secure the battery pack and ESP32 to the roof tier. Secure the L298N motor driver to the lower base plate. Bolt the HuskyLens into the front bumper mount using its supplied bracket, angled slightly downward.

### 5.4 Step-by-Step Electrical Assembly Guide

1. Power Distribution: Connect the positive side of the battery to the master switch. Then split into parallel paths to the inputs for the L298N (12V IN) and two LM2596 Buck Converters.
2. Buck Calibration: CRUCIAL STEP. Prior to connecting the logic boards, set Buck 1 to precisely 5.0V and Buck 2 to precisely 6.0V (steering servo) using a multimeter.
3. Voltage Dividers: HC-SR04 ECHO pins have 5V logic which will burn the 3.3V logic pins on ESP32 board. Connect three voltage dividers of 1kΩ and 2kΩ resistors in series between the ECHO pins and GPIOs on ESP32 board. Construct another voltage divider of 100kΩ and 22kΩ resistor for battery voltage.
4. Data Lines: Set the HuskyLens protocol to I2C from its on-device settings menu, then connect its SDA and SCL lines to the ESP32's I2C pins (GPIO21 and GPIO22). Make sure that all the components (battery, L298N, ESP32, HuskyLens, servo, sensors) are connected to one big common ground.

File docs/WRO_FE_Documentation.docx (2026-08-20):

# WRO Future Engineers 2026

Category: Future Engineers

## Table of Contents

1. Executive Summary & Vehicle Overview
2. Strategic Challenge Analysis
3. Criterion 1: Mobility & Mechanical Design
4. Criterion 2: Power & Sensor Architecture
5. Criterion 3: Software Architecture & Obstacle Strategy
6. Criterion 4: Systems Thinking & Engineering
7. Criterion 5: Reproducibility & GitHub Quality
8. Comprehensive Testing Logs & Analytics

## Executive Summary & Vehicle Overview

Yo_Bot_To_The_Future robot is one that has high performance and is made for the sole aim of addressing the problems presented by the WRO 2026 Future Engineers competition. Through the utilization of a HuskyLens AI vision sensor paired with an ESP32 microcontroller that handles every real-time control task, we achieve seamless coordination between perception and movement without ever loading the control loop with image processing.

System Parameter | Detailed Specification
Chassis | Optimized for balance between weight and strength, featuring a second layer to separate the electronic components that build this device.
Steering | The Ackermann trapezoidal linkage is driven by an analog servo which turns up to 35 degrees on either side.
Wheels | High-traction rubber treads with a 65mm diameter, 204mm circumference and predictable change in position.
Vision Processor | HuskyLens AI camera with an onboard Kendryte K210 processor, performing all colour recognition internally.
Main Controller | ESP32, dedicated to real-time decisions, PWM signal generation, and I2C polling.
Primary Sensor Input | HuskyLens in Colour Recognition mode for dynamic colour object detection.
Secondary Sensor Input | Array of HC-SR04 Ultrasonic sensors for wall collision avoidance.
Power Reservoir | Custom-made 3S 18650 lithium-ion battery pack, providing 11.1V normally, with a system that shuts it off if the voltage gets too low.

Team Picture:

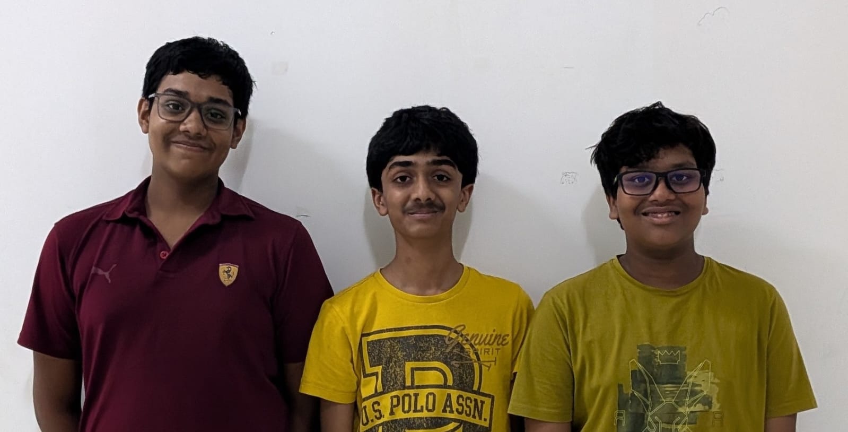
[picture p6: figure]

## Strategic Challenge Analysis

Requirements of WRO Future Engineers 2026 include the development of an autonomous car on 1/10 scale that is able to drive through a randomly created track surrounded by walls and determine its path based on colored pillars. The evaluation criteria of this competition significantly favors the teams that will be able to prove their knowledge of automotive engineering (e.g., Ackerman system).

Our strategy was built upon fundamental pillars of autonomous vehicle design:

- Deterministic Actuation: The robot's physical response to a software command must be identical every single time. This put our team in favor of Ackermann steering.
- Data Isolation: Processing a live camera feed requires massive computational thinking. If the same processor handling the camera is also responsible for generating the precise PWM pulses for the steering servo, the servo will jitter due to thread blocking. Thus, the HuskyLens handles all the image data on its own K210 processor and reports only coordinates, and the ESP32 handles the time-critical pulses.

## 1. Criterion 1: Mobility & Mechanical Design

### 1.1 Chassis Engineering & Material Selection

The chassis is considered to be the backbone of the car itself. At an early stage in our design process, we found out that a flexible chassis will lead to an error in the pitch and angle of our HuskyLens, leading to large mathematical errors in our distance estimation system. Even when the camera tilts just two degrees downwards because of heavy acceleration, the system sees objects closer than they really are.

In order to remove this problem, the chassis was designed using CAD software and then manufactured using 3D printing. We chose high density PETG filament for printing as it has better resistance to impact and glass transition temperature. The chassis has a honeycomb infill design which maximizes stiffness and maintains strength.

### 1.2 The Roof Tier Module: Iterative Evolution

In phase two of our prototype, there was one key issue identified in the design. This included electromagnetic interference and thermal saturation. The L298N H-Bridge dissipates a significant amount of heat under sustained motor load. When the logic boards sit directly beside it, that heat pools in one region of the deck. Another issue is that by putting all the wires on one layer, it became a rat's nest.

The Solution: We designed a secondary roof tier that bolts onto the chassis walls. This roof tier held the battery pack and the ESP32 microcontroller away from the lower deck. This design choice came with three benefits:

1. EMI Isolation: The sensitive logic-level I2C data lines on the roof are distanced from the noisy magnetic fields generated by the 100 RPM motors below.
2. Thermal Management: The lower deck became a wind tunnel, allowing air flow directly over the L298N heatsink.
3. Center of Mass Optimization: While raising the battery usually negatively impacts the CoM, placing it directly over the rear drive axle massively increased the normal force on the rear tires, practically eliminating wheel slip during aggressive acceleration.

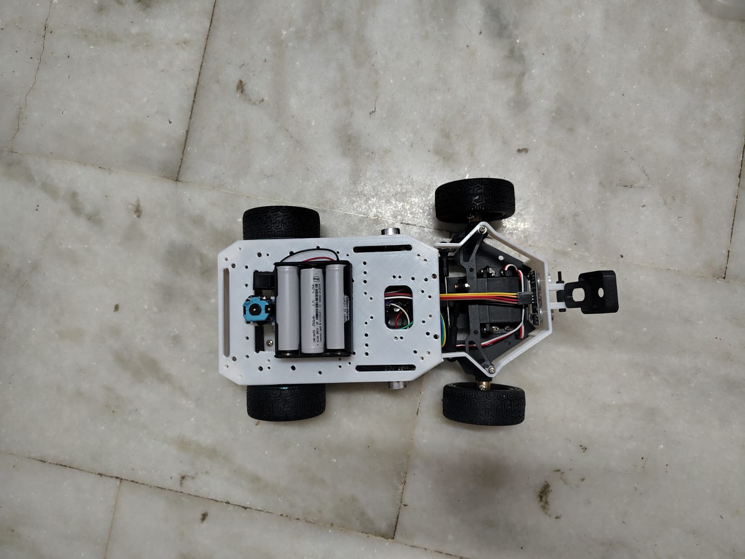
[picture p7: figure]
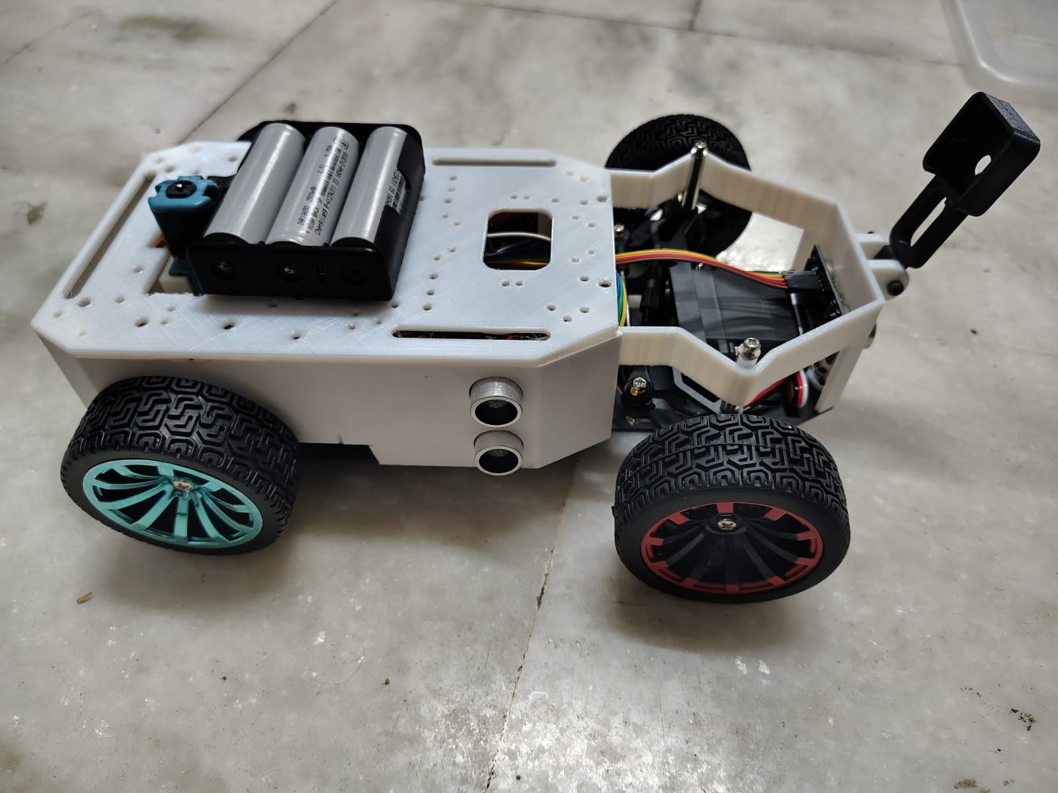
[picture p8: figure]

### 1.3 Ackermann Steering Geometry & Kinematics

In an effort to conform to the Future Engineers category rules, our car employs true steered front axle design. We chose not to use the differential or skid steering method. With the skid steering system, the wheels have to scrub against the surface to make the car turn. These forces introduce non-linear friction coefficients which nullify the accuracy of odometry measurements and make open-loop steering impossible.

A trapezoidal Ackermann steering was used in the design of the car. On a turn, the inner wheel needs to follow a smaller radius circle compared to the outer wheel. When both wheels steer at the same angle, there is bound to be slip between them. It is by this geometry that the steering linkages need to be at an angle to make sure that their geometric lines meet at the rear axle.

Mathematical Constraint:

cot(Outer_Angle) - cot(Inner_Angle) = Track_Width / Wheelbase

To prevent mechanical binding and servo stall, we implemented physical hard stops on the chassis that restrict the maximum tie-rod horizontal travel, effectively capping our maximum steering angle at precisely 35 degrees left and right. This fixed maximum allows the path-planning algorithm to rely on a hardcoded minimum turning radius.

### 1.4 Drivetrain, Propulsion, & Torque Analytics

The propulsion system in the rear end is composed of two 100 RPM geared DC motors controlled by an L298N H-Bridge controller. The choice of 100 RPM motors is not an arbitrary choice.

Speed vs Frame Processing Latency: If we take into account the speed of the robot to be 2.0 m/s and that the HuskyLens reports recognised colour blocks at roughly 20 FPS. Then, the robot travels 10 cm for every frame data collected. Thus, the faster the motors are, the greater the distance traveled between frames and hence late collision detection and wall collision. With 100 RPM motors, we achieve perfect speed synchronization with the latency of the vision module.

With a wheel diameter of 65 mm, we have a wheel circumference of 204.2 mm. For 100 RPM, the theoretical top speed is 0.34 m/s with very high torque at low speeds.

## 2. Criterion 2: Power & Sensor Architecture

### 2.1 Power Tree, Isolation, & Load Balancing

The electrical design system has been built on the basis of isolation and prevention of brown out conditions. The battery used for the power of the vehicle is a custom made 3S 18650 Lithium-Ion battery which provides 12.6 volts of power output with nominal voltage of 11.1 volts.

The power tree splits immediately after the master fuse and emergency kill switch:

- Branch 1 (High Power): The uncontrolled 12.6V feeds directly to the L298N H-Bridge motor driver. This provides the drive motors with access to immense burst currents in order to accelerate.
- Branch 2 (Servo Logic): The 12.6V is directed towards a highly efficient buck converter which drops the voltage to exactly 6.0V. The 6V rail powers the steering servo alone. During stall against a wall, the servo pulls more than 1.5Amps in the blink of an eye. With the help of this buck converter, this current spike does not go to the microcontroller.
- Branch 3 (Digital Logic): The second 5V step-down power converter powers the ESP32 microcontroller and the HuskyLens to provide a pure power supply without any ripple to prevent the controller from randomly rebooting during operation. The HuskyLens draws roughly 320mA while actively recognising, so it is fed from this regulated rail rather than from the ESP32's own 5V pin.

### 2.2 Li-ion Battery Discharge Characteristics

Lithium Ion is unstable when it is over-discharged. If the pack voltage is less than 9.0 volts, then there will be some chemical damage. We have designed an impedance voltage divider, which is connected to the ESP ADC directly. The ESP keeps monitoring the pack voltage. If it drops below 9.5 volts, then an interrupt signal is generated, and the H-bridge circuit stops working.

### 2.3 Sensor Topology: Vision vs. Proximity

Primary Vision (HuskyLens): The HuskyLens has been placed on a specially designed bracket fixed onto the front bumper, which has been calibrated to view the horizon of the field wall and base of the colored obstacle poles. The visual sense is used to keep the vehicle in its path and classify obstacles. Because the HuskyLens carries its own K210 vision processor, it returns only a small list of recognised block coordinates over I2C rather than a raw video stream, which is what allows a single microcontroller to run the whole vehicle.

Secondary Proximity (Ultrasonic): The ultrasonic sensors HC-SR04 were attached to the front and side wings of the chassis. These use an entirely different physical approach (sound waves compared to photons). In case the camera cannot see due to a bright overhead light (specular glare off the mat), the ultrasonic sensors serve as a fallback. We activate the sensors in a round robin fashion to avoid acoustic interference (the echo of one ping heard by the other sensor).

### 2.4 Comprehensive Pinout & Wiring Manifesto

Robotic reliability is 90% wiring. Each and every wire on this robot is crimped, strain-relieved, and tagged.


## 3. Criterion 3: Software Architecture & Obstacle Strategy

### 3.1 Vision Offloading: Smart Sensor & Real-Time Controller

A general-purpose microcontroller does not have the capability to deal with raw video signals. A single-board computer running a full operating system, on the other hand, has issues with timing of the PWM signal because of the overhead of the OS scheduler. This problem is solved in our software architecture by pushing the vision workload into the sensor itself.

The HuskyLens is responsible for executing the recognition work. Its onboard K210 processor runs the colour recognition model, so the heavy per-pixel maths never touches our control loop.

The ESP32 handles the compiled C++ program. It is the brain stem of our project. It just deals with the current time frame and thinks only about the following questions: How many microseconds does my signal need to be right now? What is the current battery voltage? Where did the HuskyLens last report a coloured block?

### 3.2 Vision Pipeline & Colour Recognition

Our system for obstacle avoidance uses the HuskyLens in Colour Recognition mode. Colours are taught to the sensor during setup under arena-representative lighting, and the K210 performs its thresholding internally in a hue-based colour space, which is much more resilient to changes in ambient light conditions than raw RGB comparison.

1. Learning: Before a run, the red pillar is learned as ID 1 and the green pillar as ID 2. The learned models are stored in the HuskyLens's own flash memory, so they survive a power cycle.
2. Block Extraction: For every frame, the HuskyLens isolates the largest contiguous region matching a learned colour and returns a bounding block containing its ID, centre X, centre Y, width and height.
3. Spatial Mapping: The ESP32 finds the obstacle's position by checking where the centre of the returned block is compared to the centre of the camera frame (160 on a 320-pixel-wide frame). It also estimates how far away it is based on the size of the block. A bigger block means the obstacle is closer.

### 3.3 State Machine Topology & Transitions

The vehicle operates autonomously via a finite state machine, ensuring predictable behavior under all conditions:

- STATE_INIT: Hardware boot sequence, I2C bus scan, HuskyLens handshake and mode check, battery voltage check.
- STATE_WAIT: Vehicle is armed but stationary, polling the physical start button.
- STATE_LANE_FOLLOW: Default active state. Uses ultrasonic sensors and vision to maintain a central vector between the track walls.
- STATE_AVOID_GREEN: Triggered when a green block's area exceeds the threshold. Generates a steering vector to pass the obstacle on the designated correct side, overriding lane-following.
- STATE_AVOID_RED: Same logic as green, but generating an inverted steering vector to pass on the opposite side.
- STATE_RECOVERY: Triggered if front ultrasonic sensors detect an immediate wall (< 10cm) or if the HuskyLens stops responding on the I2C bus. The ESP32 autonomously halts the motors, reverses slightly, and straightens the steering to prevent a crash.

### 3.4 Control Theory: PID Controller for Lane Centering

When the camera does not see an obstacle, the robot defaults to following the walls using a Proportional-Integral-Derivative (PID) control loop based on the lateral ultrasonic sensors.

Error = (Distance_Left_Wall - Distance_Right_Wall) P_Out = Kp * Error I_Out = Ki * Integral(Error) D_Out = Kd * Derivative(Error) Steering_Angle = P_Out + I_Out + D_Out

We carefully adjusted these settings. Kp controls how strongly the robot turns back toward the center. Kd helps smooth out the turns and stops the robot from wobbling on straight paths. Ki is kept very low to avoid problems when the robot takes sharp 90° turns.

## 4. Criterion 4: Systems Thinking & Engineering Decisions
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

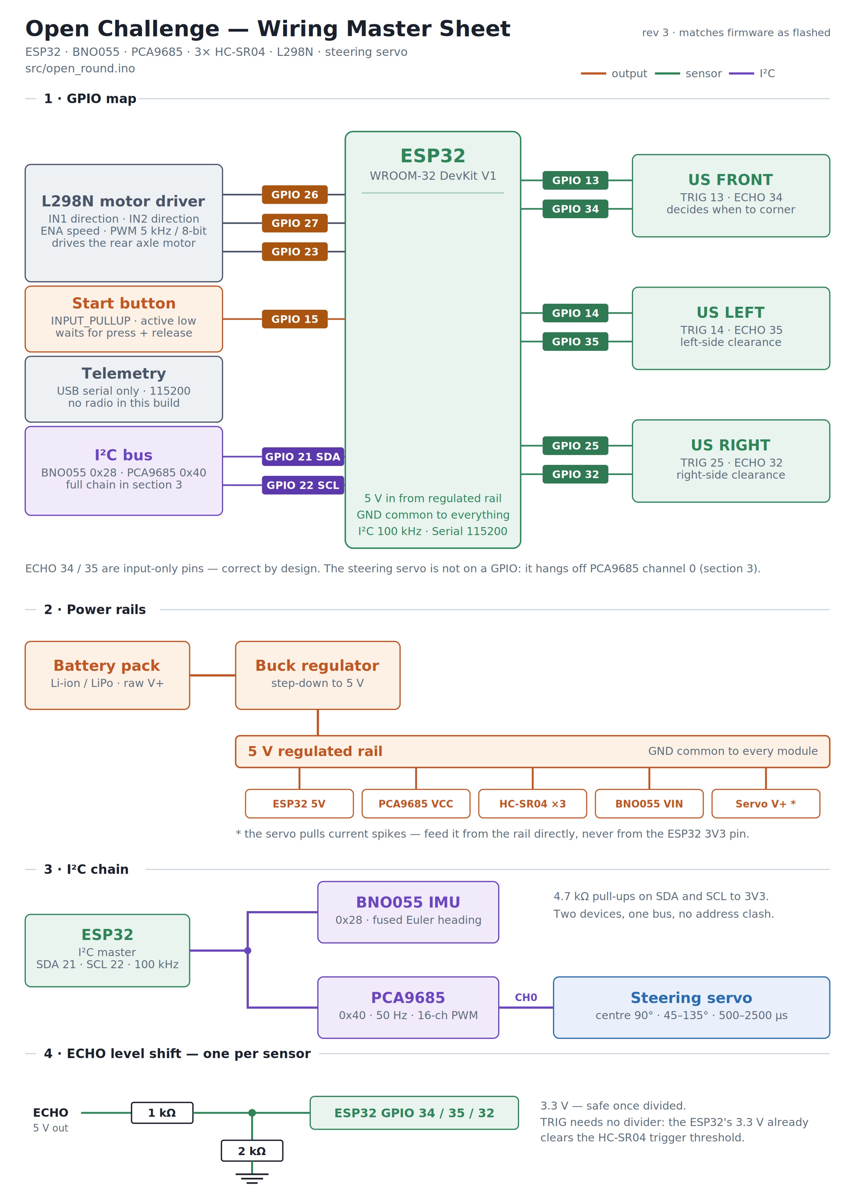
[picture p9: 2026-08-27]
pinout_open_round.png

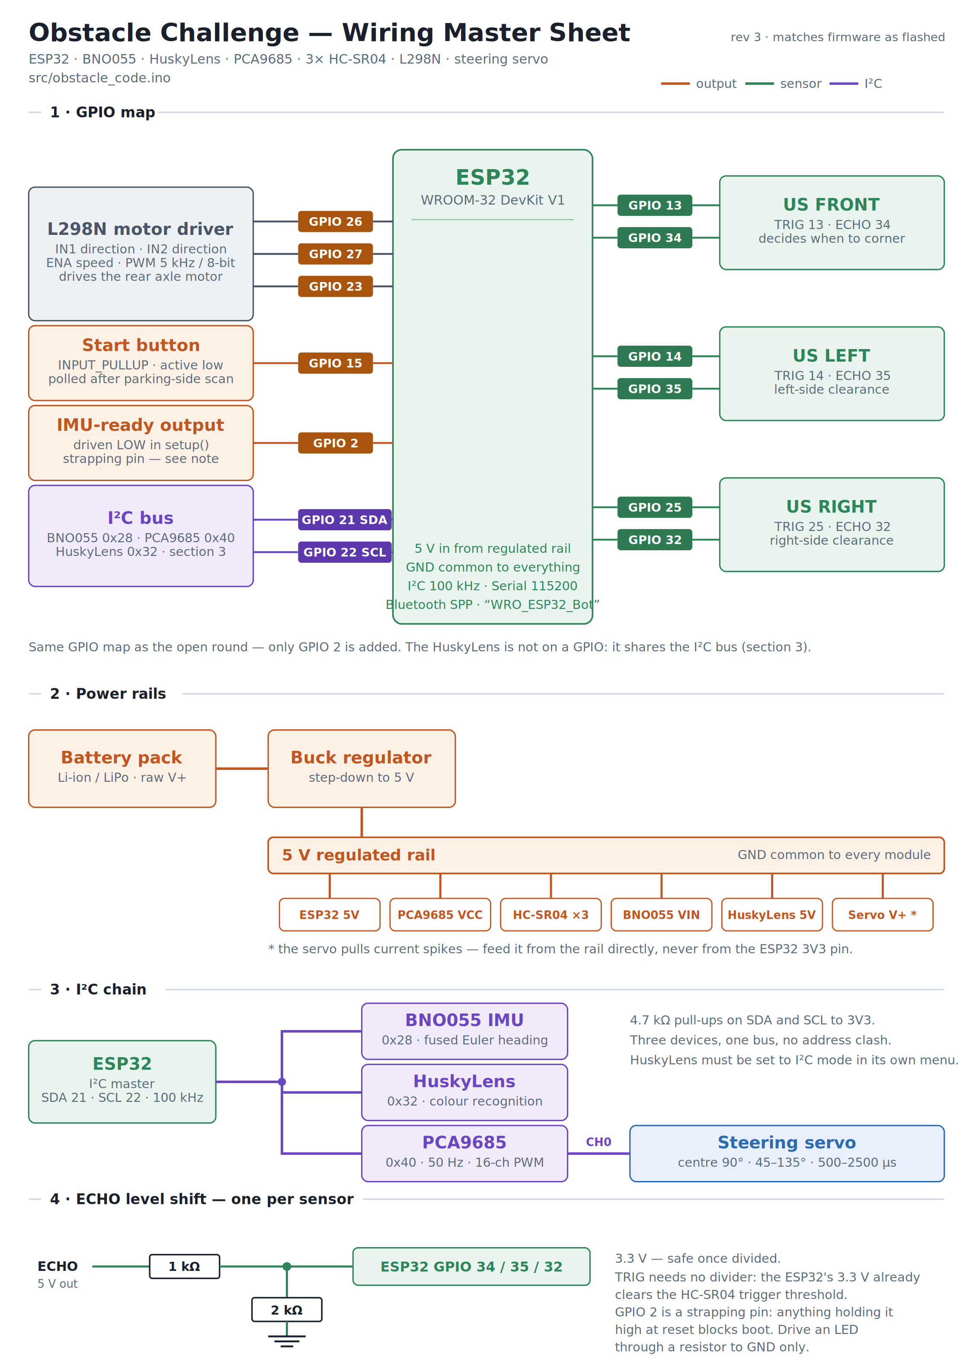
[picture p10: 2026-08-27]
pinout_obstacle_challenge.png

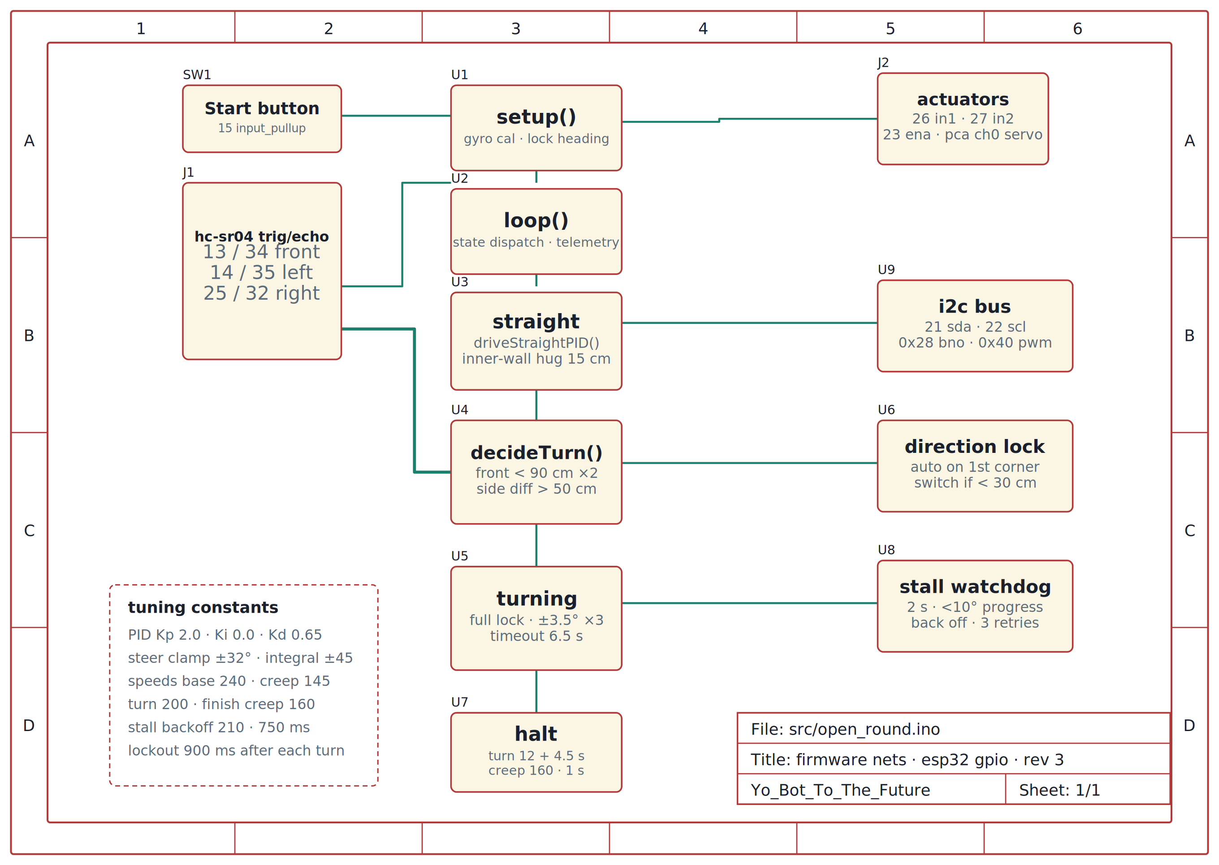
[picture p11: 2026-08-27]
openchallenge_scheme.png

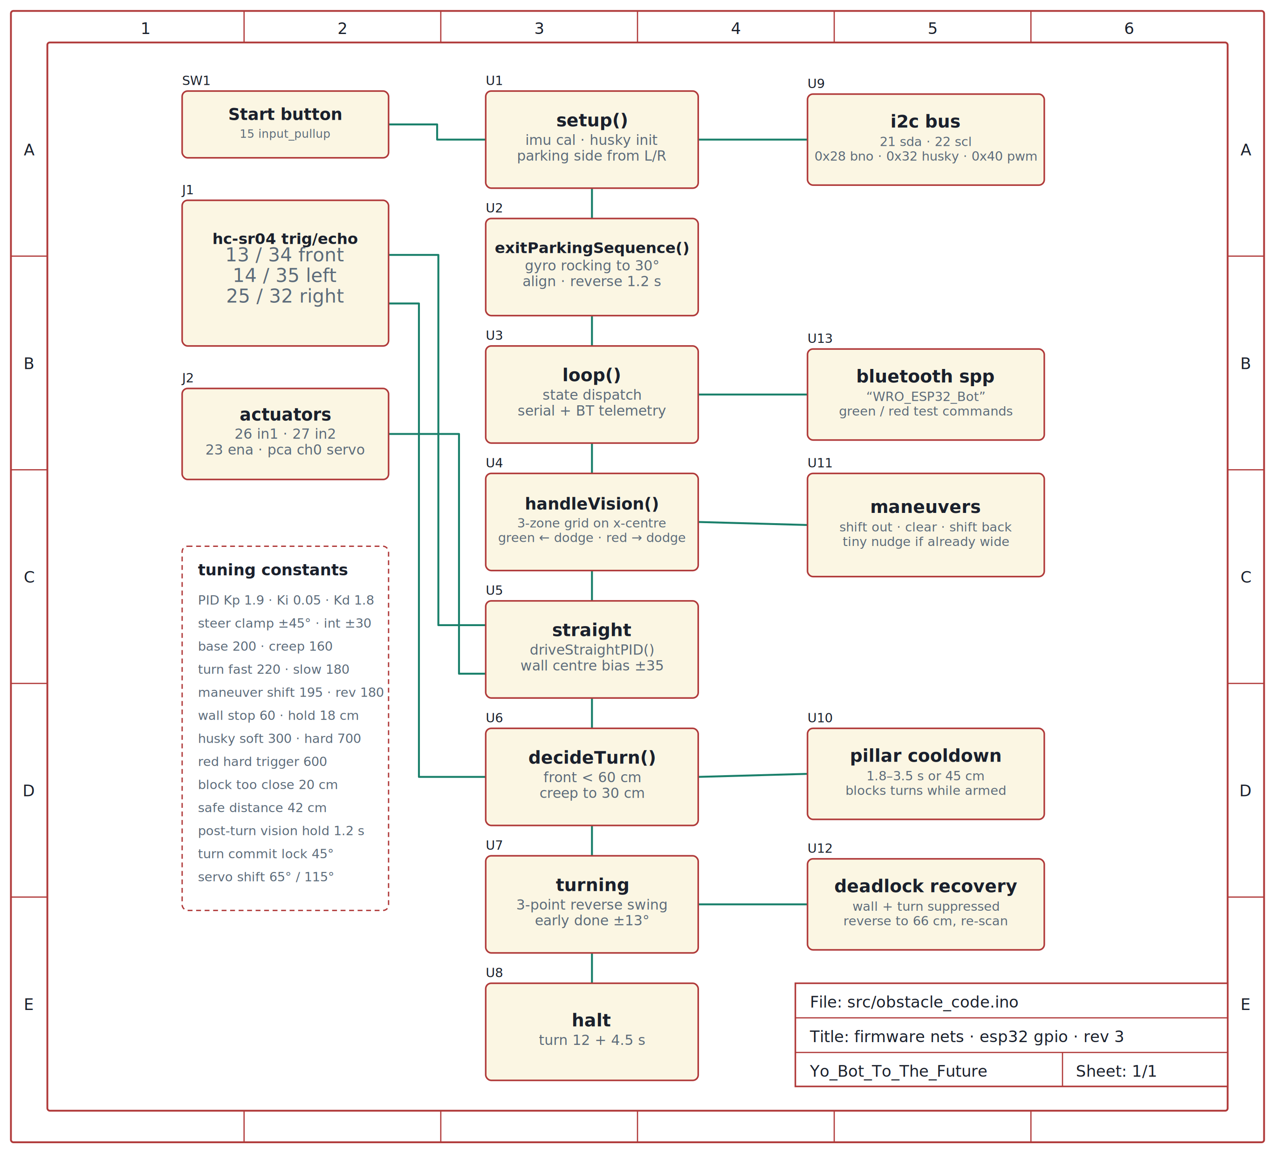
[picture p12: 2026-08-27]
obstacle_challenge_scheme.png

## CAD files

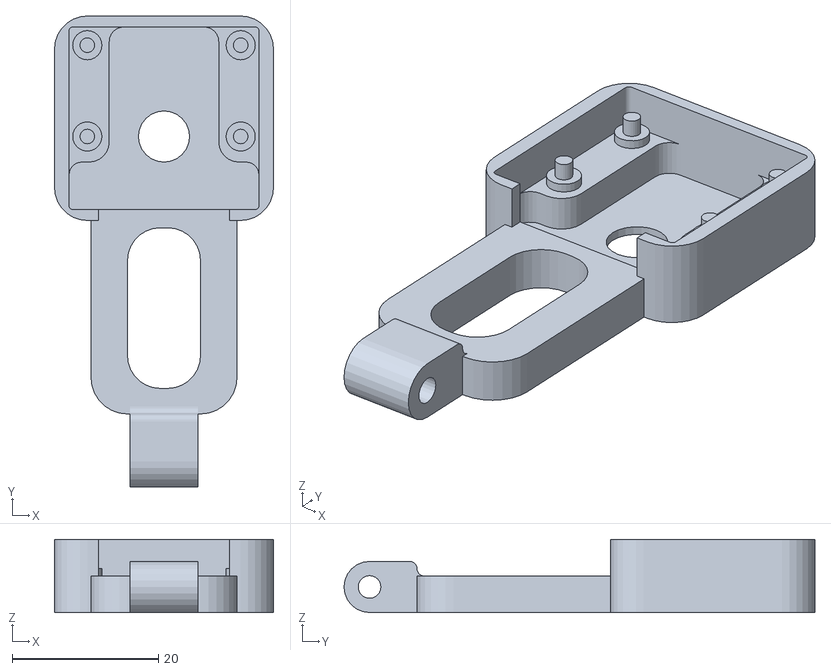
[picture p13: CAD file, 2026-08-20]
models/camera_front_box_v003.stl
30.0 x 64.5 x 10.0

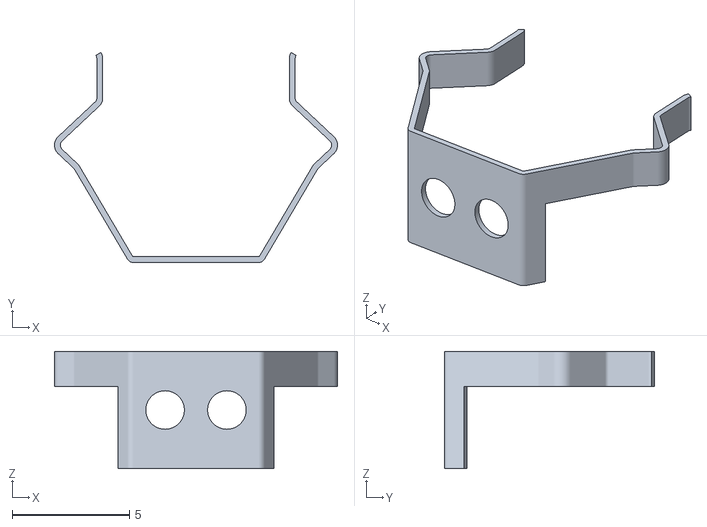
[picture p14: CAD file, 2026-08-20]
models/frontcage.stl
12.1 x 8.95 x 5.00

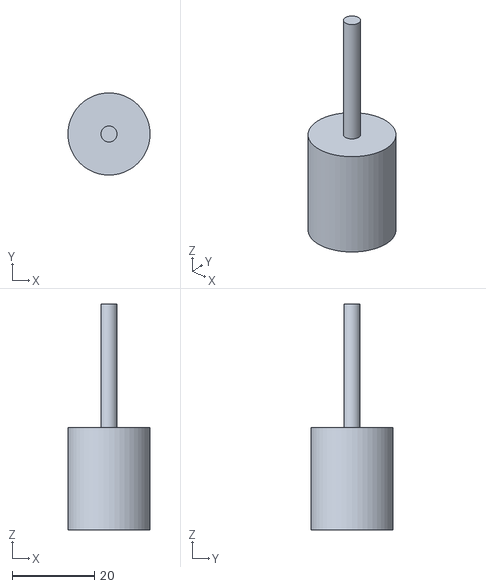
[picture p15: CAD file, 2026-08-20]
models/axle_adaptor.stl
20.0 x 20.0 x 55.0

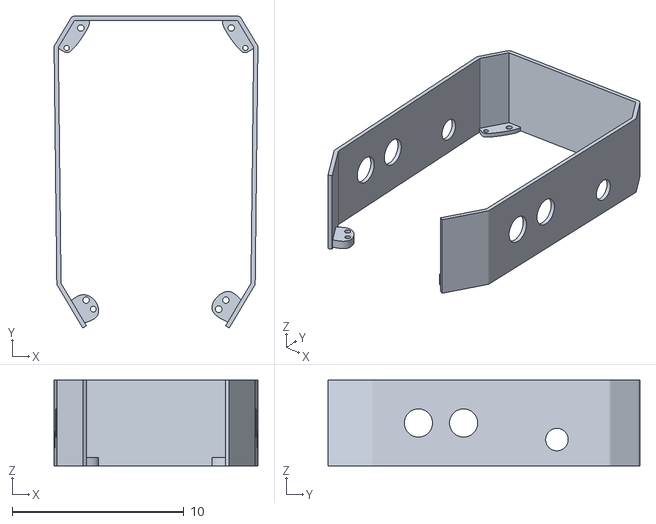
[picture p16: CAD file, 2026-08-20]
models/back_cage.stl
11.9 x 18.2 x 5.00

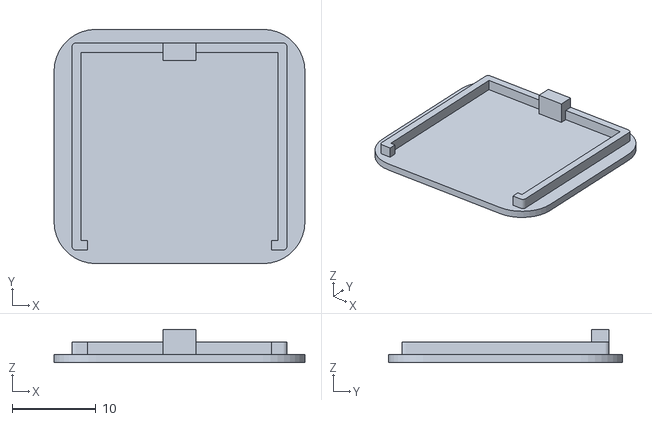
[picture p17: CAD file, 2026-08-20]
models/camera_back_cover_v002.stl
30.0 x 28.0 x 4.00

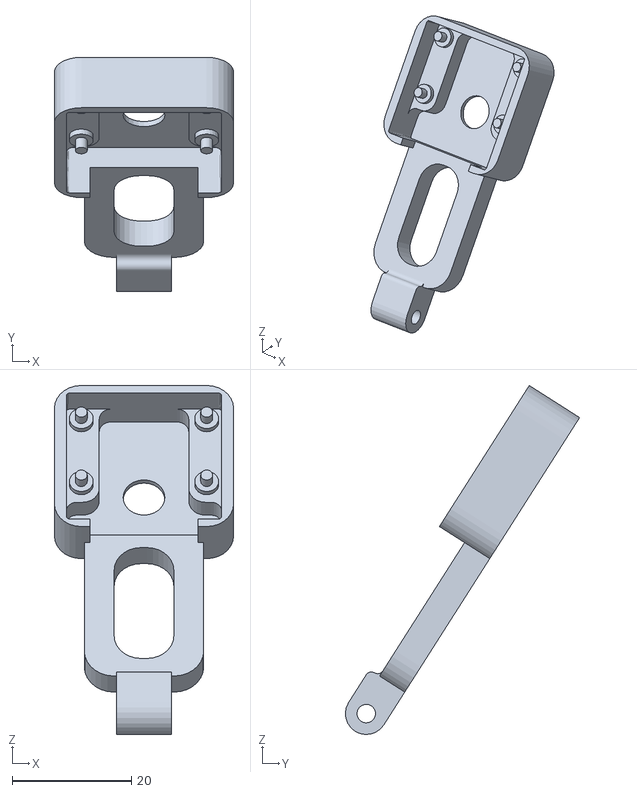
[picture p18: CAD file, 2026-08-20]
models/camera_pi_mount.stl
30.0 x 39.2 x 58.4

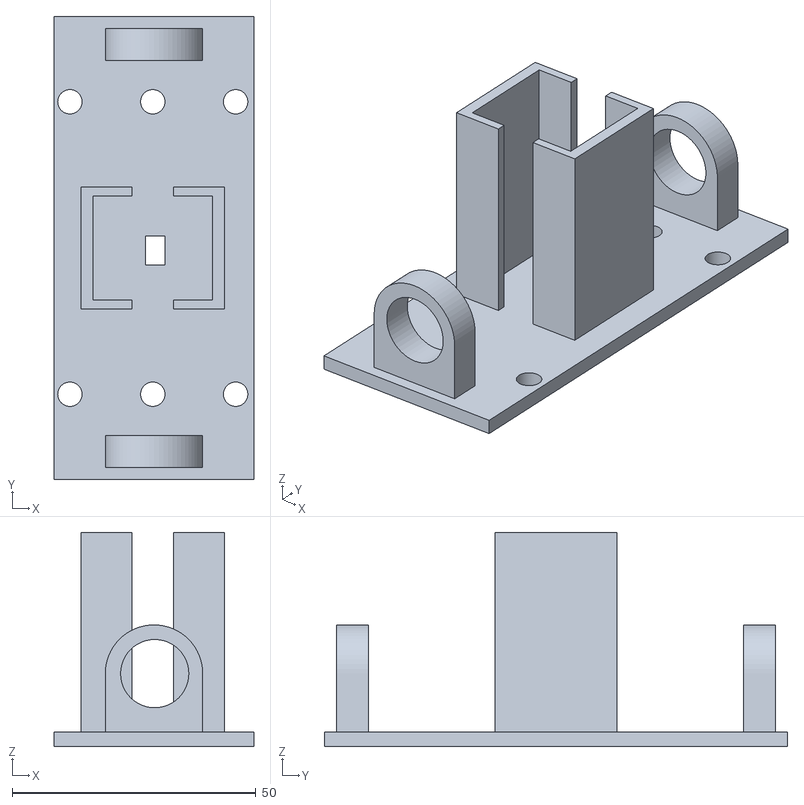
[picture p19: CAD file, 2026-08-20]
models/motor mount (4).stl
41.0 x 95.0 x 44.0

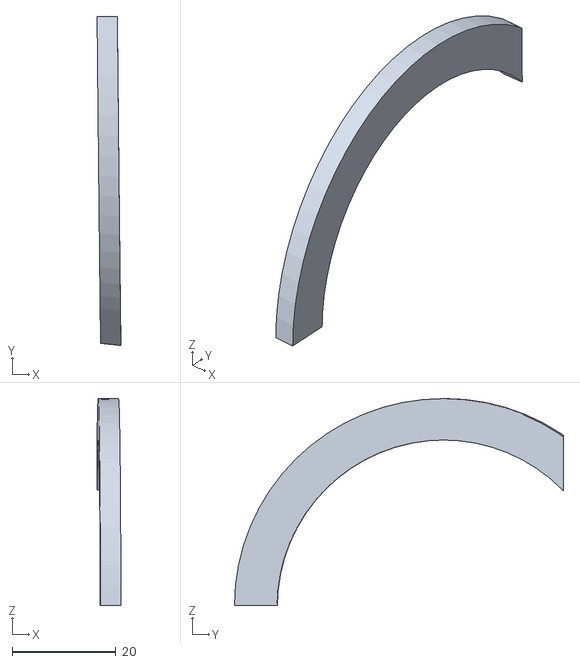
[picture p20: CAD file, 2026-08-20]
models/wheelcover.stl
4.62 x 63.6 x 40.0

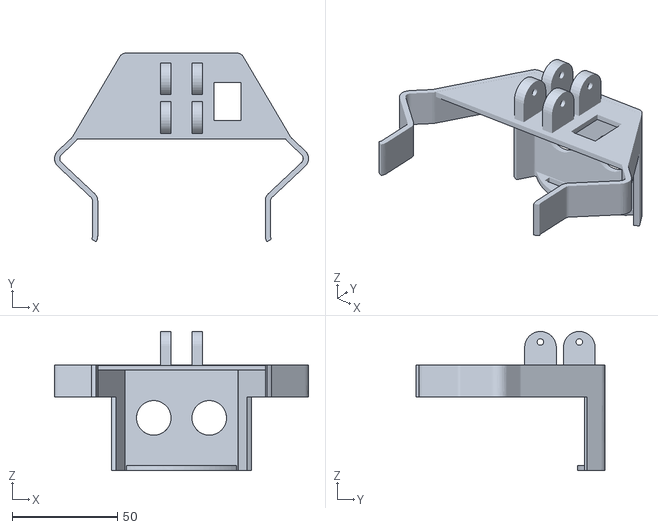
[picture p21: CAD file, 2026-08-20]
models/husky lens mount (1).stl
120.5 x 89.5 x 66.0

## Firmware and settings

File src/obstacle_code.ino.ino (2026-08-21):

/* =============================================================================
 * WRO FUTURE ENGINEERS — OBSTACLE CHALLENGE FIRMWARE
 * ESP32 | BNO055 | HuskyLens | PCA9685-style servo steering | 3x HC-SR04
 * ============================================================================= */

#include <Arduino.h>
#include <ESP32Servo.h>
#include <Wire.h>
#include <Adafruit_Sensor.h>
#include <Adafruit_BNO055.h>
#include <utility/imumaths.h>
#include "HUSKYLENS.h"

// ==============================
// Hardware Pins
// ==============================
#define IN1 13
#define IN2 12
#define ENA 25
#define SERVO_PIN 4

#define TRIG_FRONT 5
#define ECHO_FRONT 18
#define TRIG_RIGHT 17
#define ECHO_RIGHT 16
#define TRIG_LEFT 26
#define ECHO_LEFT 27

// ==============================
// Turn Stop Settings
// ==============================
int TURN = 0;
#define STOP_AFTER_TIME 4500
#define STOP_BOT_AFTER_TURNS 12
unsigned long turnStartTime = 0;

// ==============================
// Servo Constraints
// ==============================
#define SERVO_CENTER_DEG   90
#define SERVO_MIN_DEG      28
#define SERVO_MAX_DEG      142
#define SERVO_SHIFT_LEFT   40
#define SERVO_SHIFT_RIGHT  148

// ==============================
// Sensors
// ==============================
Servo steeringServo;
Adafruit_BNO055 bno = Adafruit_BNO055(55, 0x28, &Wire);
HUSKYLENS huskylens;

#define ID_GREEN 1
#define ID_RED 2
#define ID_MAGENTA 3

// Vision thresholds (Adjusted to trigger earlier to prevent dragging pillars)
#define HUSKY_SOFT_TRIGGER 150   
#define HUSKY_AREA_TRIGGER 3000  

// ==============================
// Drive params
// ==============================
#define BASE_SPEED   135
#define TURN_SPEED   120
#define SHIFT_SPEED  130
#define WALL_STOP_DIST 90
#define TURN_DONE_TOL  3

// ==============================
// Pillar cooldown / lockout
// ==============================
#define PILLAR_COOLDOWN_MS      1800   
#define PILLAR_COOLDOWN_MAX_MS  3500   
#define EST_CM_PER_S_AT_BASE    35.0f  
#define PILLAR_COOLDOWN_CM      45.0f  

// ==============================
// Camera gating & Creeping
// ==============================
#define PILLAR_VIEW_LATCH_MS    300    
#define CREEP_SPEED             110    
#define WALL_HOLD_DIST          18.0f  // Deadlock trigger distance

float Kp = 1.4, Ki = 0.05, Kd = 1.5;
float headingError, lastError = 0, integral = 0;
float targetHeading = 0;

enum State { STRAIGHT, TURNING };
State state = STRAIGHT;
float turnTarget = 0;

// ==============================
// Monitoring Variables
// ==============================
unsigned long lastSerialTime = 0;
int currentSteerDeg = SERVO_CENTER_DEG;
int currentMotorSpeed = 0;
float frontDist = 999, leftDist = 999, rightDist = 999;
bool isBlockInSight = false;

// ==============================
// State Variables
// ==============================
unsigned long lastPillarSeenMs      = 0;     
bool          pillarCooldownArmed   = false;
unsigned long pillarCooldownStartMs = 0;
float         cooldownTravelCm      = 0;
unsigned long lastTravelUpdateMs    = 0;

// ==============================
// Prototypes
// ==============================
void  setSteeringDeg(int angleDeg);
void  motorForward(int speed);
void  motorBackward(int speed);
void  motorStop();
float readDistanceCM(int trigPin, int echoPin);
float getHeading();
float headingDiff(float target, float current);
void  calibrateIMU();
void  driveStraightPID();
void  decideTurn();
void  executeTurn();
void  preTurnWideArc(bool isTurningRight);
void  printTelemetry();
void  executeGreenManeuver();
void  executeRedManeuver();
bool  handleVision();
bool  scanForPillar(int &id, int &x, int &area);
bool  pillarInView();
bool  pillarVisibleNow();
bool  pillarCooldownActive();
void  armPillarCooldown();
void  updateTravelEstimate();
bool  turnAllowed();
void  executeDeadlockRecovery();

// ==============================
// Setup
// ==============================
void setup() {
  Serial.begin(115200);
  Wire.begin();
  delay(1000);

  pinMode(TRIG_FRONT, OUTPUT); pinMode(ECHO_FRONT, INPUT);
  pinMode(TRIG_LEFT, OUTPUT);  pinMode(ECHO_LEFT, INPUT);
  pinMode(TRIG_RIGHT, OUTPUT); pinMode(ECHO_RIGHT, INPUT);

  pinMode(IN1, OUTPUT);
  pinMode(IN2, OUTPUT);
  pinMode(ENA, OUTPUT);

  steeringServo.attach(SERVO_PIN);
  setSteeringDeg(SERVO_CENTER_DEG);
  delay(500);

  bool bnoOK = false;
  for (int i = 0; i < 5 && !bnoOK; i++) {
    bnoOK = bno.begin();
    if (!bnoOK) { Serial.println("BNO055 retry..."); delay(500); }
  }
  if (!bnoOK) {
    Serial.println("BNO055 not detected after retries — check wiring/power.");
    while (1) delay(10);
  }
  bno.setExtCrystalUse(true);
  delay(800);

  delay(1500); // HuskyLens boot stabilization
  while (!huskylens.begin(Wire)) {
    Serial.println("HuskyLens failed! Check wiring.");
    delay(500);
  }
  huskylens.writeAlgorithm(ALGORITHM_COLOR_RECOGNITION);

  calibrateIMU();

  targetHeading = getHeading();
  lastTravelUpdateMs = millis();

  motorForward(0);
  Serial.printf("--- ROBOT READY FOR TRACK --- initial targetHeading %.1f\n", targetHeading);
  delay(2000);
}

// ==============================
// Main Loop
// ==============================
void loop() {
  if (Serial.available() > 0) {
    String input = Serial.readStringUntil('\n');
    input.trim();
    if (input.equalsIgnoreCase("green")) executeGreenManeuver();
    if (input.equalsIgnoreCase("red")) executeRedManeuver();
  }

  updateTravelEstimate();   

  if (TURN == STOP_BOT_AFTER_TURNS && millis() - turnStartTime >= STOP_AFTER_TIME) {
    motorStop();
    setSteeringDeg(SERVO_CENTER_DEG);
    Serial.println("\n--- BOT STOPPED ---");
    while (1) delay(10);
  }

  // ==========================================================
  // STRICT STATE MACHINE: Camera is BLIND during turns
  // ==========================================================
  if (state == STRAIGHT) {
    
    // 1. Process Vision ONLY when driving straight
    bool cameraInControl = handleVision();
    if (cameraInControl) {
      printTelemetry();
      return; // Skip wall detection while dodging
    }

    // 2. Normal Wall Tracking
    frontDist = readDistanceCM(TRIG_FRONT, ECHO_FRONT);
    driveStraightPID();   

    bool wallAhead = (frontDist > 5 && frontDist < WALL_STOP_DIST);
    if (!wallAhead) {
        printTelemetry();
        return;
    }

    // 3. Wall Detected - Check if we are allowed to turn
    if (!turnAllowed()) {
      if (frontDist <= WALL_HOLD_DIST) {
        // We are trapped against a wall by a cooldown. Recover physically!
        executeDeadlockRecovery();
      } else {
        motorForward(CREEP_SPEED); // Creep slowly until cooldown expires
      }
      printTelemetry();
      return;
    }

    // 4. Confirm Wall & Initiate Turn
    delay(30);
    float confirmDist = readDistanceCM(TRIG_FRONT, ECHO_FRONT);
    if (confirmDist > 5 && confirmDist < WALL_STOP_DIST) {
      motorStop();
      delay(200);

      // Final gate check before going blind
      if (pillarVisibleNow() || !turnAllowed()) {
        Serial.println("[GATE] turn ABORTED BEFORE START (Pillar/Cooldown Detected)");
        printTelemetry();
        return;
      }

      decideTurn();
    }
  } 
  else if (state == TURNING) {
    // Completely bypass camera and distance checks, trust the IMU exclusively
    executeTurn();
  }

  printTelemetry();
}

// =====================================================================
// Deadlock Recovery Failsafe
// =====================================================================
void executeDeadlockRecovery() {
  Serial.println("\n*** DEADLOCK DETECTED: Wall reached but turn suppressed. ***");
  Serial.println("*** REVERSING UNTIL 66CM CLEARANCE REACHED ***");
  
  setSteeringDeg(SERVO_CENTER_DEG);
  motorBackward(BASE_SPEED);

  unsigned long reverseStart = millis();
  float currentDist = readDistanceCM(TRIG_FRONT, ECHO_FRONT);

  // Reverses safely away from the wall
  while (currentDist < 66.0f && (millis() - reverseStart < 3000)) {
    currentDist = readDistanceCM(TRIG_FRONT, ECHO_FRONT);
    delay(20); 
  }

  motorStop();
  delay(200); 

  // Force the logic gates open since we have physical space now
  pillarCooldownArmed = false; 
  Serial.println("Deadlock cleared physically. Initiating standard cornering.");
  decideTurn(); 
}

// =====================================================================
// Pillar cooldown / lockout 
// =====================================================================
void armPillarCooldown() {
  pillarCooldownArmed   = true;
  pillarCooldownStartMs = millis();
  cooldownTravelCm      = 0;          
  lastTravelUpdateMs    = millis();   
}

void updateTravelEstimate() {
  unsigned long now = millis();
  unsigned long dtMs = now - lastTravelUpdateMs;
  lastTravelUpdateMs = now;

  if (dtMs == 0 || dtMs > 1000) return;   
  if (currentMotorSpeed <= 0) return;

  float dt = dtMs / 1000.0f;
  cooldownTravelCm += ((float)currentMotorSpeed / (float)BASE_SPEED)
                      * EST_CM_PER_S_AT_BASE * dt;
}

bool pillarCooldownActive() {
  if (!pillarCooldownArmed) return false;

  unsigned long elapsed = millis() - pillarCooldownStartMs;

  if (elapsed >= PILLAR_COOLDOWN_MAX_MS) {
    pillarCooldownArmed = false;
    return false;
  }

  if (elapsed < PILLAR_COOLDOWN_MS) return true;
  if (cooldownTravelCm < PILLAR_COOLDOWN_CM) return true;

  pillarCooldownArmed = false;
  return false;
}

// =====================================================================
// Pre-emptive turn gate
// =====================================================================
bool pillarInView() {
  if (lastPillarSeenMs == 0) return false;
  return (millis() - lastPillarSeenMs) < PILLAR_VIEW_LATCH_MS;
}

bool turnAllowed() {
  return (!pillarInView()) && (!pillarCooldownActive());
}

bool pillarVisibleNow() {
  int id = 0, x = 160, area = 0;
  if (!scanForPillar(id, x, area)) return false;
  if (area <= HUSKY_SOFT_TRIGGER) return false;
  if (id != ID_RED && id != ID_GREEN) return false;   

  lastPillarSeenMs = millis();
  armPillarCooldown();
  return true;
}

// =====================================================================
// Vision
// =====================================================================
bool scanForPillar(int &id, int &x, int &area) {
  huskylens.request();
  if (!huskylens.available()) return false;

  int largestArea = 0;
  int detectedID = 0;
  int detectedX = 160; 

  while (huskylens.available()) {
    HUSKYLENSResult result = huskylens.read();
    int a = result.width * result.height;
    if (a > largestArea) {
      largestArea = a;
      detectedID = result.ID;
      detectedX = result.xCenter;
    }
  }

  id = detectedID; x = detectedX; area = largestArea;
  return true;
}

bool handleVision() {
  int detectedID = 0, detectedX = 160, largestArea = 0;

  if (!scanForPillar(detectedID, detectedX, largestArea)) {
    isBlockInSight = false;
    return false;
  }

  isBlockInSight = (largestArea > HUSKY_SOFT_TRIGGER);
  if (!isBlockInSight) return false;

  if (detectedID == ID_MAGENTA) return false; 
  if (detectedID != ID_RED && detectedID != ID_GREEN) return false; 

  lastPillarSeenMs = millis();
  armPillarCooldown();

  if (largestArea > HUSKY_AREA_TRIGGER) {
    if (detectedID == ID_GREEN) executeGreenManeuver();
    else executeRedManeuver();
    return true;
  }

  int intensity = map(largestArea, HUSKY_SOFT_TRIGGER, HUSKY_AREA_TRIGGER, 8, 35);
  intensity = constrain(intensity, 8, 35);
  int steerAdj = 0;

  if (detectedID == ID_RED) {
    if (detectedX < 106) steerAdj = intensity;
    else if (detectedX < 213) steerAdj = (int)(intensity * 0.7);
    else steerAdj = (int)(intensity * 0.4);
  } else {
    if (detectedX > 213) steerAdj = -intensity;
    else if (detectedX > 106) steerAdj = (int)(-intensity * 0.7);
    else steerAdj = (int)(-intensity * 0.4);
  }

  setSteeringDeg(SERVO_CENTER_DEG + steerAdj);
  motorForward(BASE_SPEED);
  return true;
}

// ---------------- Maneuver Sequences ----------------
void executeGreenManeuver() {
  Serial.println("\n--- GREEN MANEUVER: SHIFT LEFT ---");
  motorStop(); delay(200);

  setSteeringDeg(SERVO_CENTER_DEG);
  motorBackward(BASE_SPEED);
  delay(400); // Back up slightly to clear the pillar
  motorStop(); delay(200);

  setSteeringDeg(SERVO_SHIFT_LEFT);
  motorForward(SHIFT_SPEED);
  delay(650); // Increased shift duration to widen the berth

  setSteeringDeg(SERVO_CENTER_DEG);
  motorForward(SHIFT_SPEED);
  delay(400);

  setSteeringDeg(SERVO_SHIFT_RIGHT);
  motorForward(SHIFT_SPEED);
  delay(650); // Matches the left shift

  setSteeringDeg(SERVO_CENTER_DEG);
  motorStop(); delay(150);

  integral = 0; lastError = 0;
  state = STRAIGHT;
  armPillarCooldown();
  lastPillarSeenMs = millis();
}

void executeRedManeuver() {
  Serial.println("\n--- RED MANEUVER: SHIFT RIGHT ---");
  motorStop(); delay(200);

  setSteeringDeg(SERVO_CENTER_DEG);
  motorBackward(BASE_SPEED);
  delay(400); // Back up slightly to clear the pillar
  motorStop(); delay(200);

  setSteeringDeg(SERVO_SHIFT_RIGHT);
  motorForward(SHIFT_SPEED);
  delay(650); // Increased shift duration to widen the berth

  setSteeringDeg(SERVO_CENTER_DEG);
  motorForward(SHIFT_SPEED);
  delay(400);

  setSteeringDeg(SERVO_SHIFT_LEFT);
  motorForward(SHIFT_SPEED);
  delay(650); // Matches the right shift

  setSteeringDeg(SERVO_CENTER_DEG);
  motorStop(); delay(150);

  integral = 0; lastError = 0;
  state = STRAIGHT;
  armPillarCooldown();
  lastPillarSeenMs = millis();
}

// ---------------- Serial Monitoring ----------------
void printTelemetry() {
  if (millis() - lastSerialTime < 150) return;
  lastSerialTime = millis();

  float currHeading = getHeading();
  Serial.print(state == STRAIGHT ? "[STR] " : "[TRN] ");
  Serial.printf("F:%4.1fcm L:%4.1fcm R:%4.1fcm | ", frontDist, leftDist, rightDist);
  Serial.printf("H_Cur:%5.1f H_Tgt:%5.1f Err:%5.1f | ", currHeading, targetHeading, headingError);
  Serial.printf("Steer:%3d MtrSpd:%3d BlkInSight:%d | CD:%d(%.0fcm)\n", 
                currentSteerDeg, currentMotorSpeed, isBlockInSight, pillarCooldownArmed ? 1 : 0, cooldownTravelCm);
}

// ---------------- Ultrasonic ----------------
float readDistanceCM(int trigPin, int echoPin) {
  digitalWrite(trigPin, LOW);
  delayMicroseconds(2);
  digitalWrite(trigPin, HIGH);
  delayMicroseconds(10);
  digitalWrite(trigPin, LOW);
  long duration = pulseIn(echoPin, HIGH, 15000);
  if (duration == 0) return 999;
  return duration * 0.0343f / 2.0f;
}

// ---------------- IMU Calibration & Data ----------------
void calibrateIMU() {
  uint8_t system, gyro, accel, mag;
  system = gyro = accel = mag = 0;

  Serial.println("\n--- Calibrating IMU ---");
  while (gyro < 3) {
    bno.getCalibration(&system, &gyro, &accel, &mag);
    delay(200);
  }
  Serial.println("Gyroscope Calibrated Successfully!\n");
}

float getHeading() {
  imu::Vector<3> e = bno.getVector(Adafruit_BNO055::VECTOR_EULER);
  return e.x();
}

float headingDiff(float target, float current) {
  float d = target - current;
  while (d > 180) d -= 360;
  while (d < -180) d += 360;
  return d;
}

// ---------------- Steering ----------------
void setSteeringDeg(int angleDeg) {
  currentSteerDeg = constrain(angleDeg, SERVO_MIN_DEG, SERVO_MAX_DEG);
  steeringServo.write(currentSteerDeg);
}

// ---------------- Motor ----------------
void motorForward(int speed) {
  currentMotorSpeed = speed;
  digitalWrite(IN1, HIGH); digitalWrite(IN2, LOW);
  analogWrite(ENA, speed);
}

void motorBackward(int speed) {
  currentMotorSpeed = -speed;
  digitalWrite(IN1, LOW); digitalWrite(IN2, HIGH);
  analogWrite(ENA, speed);
}

void motorStop() {
  currentMotorSpeed = 0;
  digitalWrite(IN1, LOW); digitalWrite(IN2, LOW);
  analogWrite(ENA, 0);
}

// ---------------- Straight-line heading-hold PID ----------------
void driveStraightPID() {
  float current = getHeading();
  headingError = headingDiff(targetHeading, current);

  integral += headingError;
  integral = constrain(integral, -30, 30);
  float derivative = headingError - lastError;
  lastError = headingError;

  float correction = Kp * headingError + Ki * integral + Kd * derivative;
  int steerDeg = SERVO_CENTER_DEG + constrain((int)correction, -30, 30);

  setSteeringDeg(steerDeg);
  motorForward(BASE_SPEED);
}

// =====================================================================
// PRE-TURN WIDE ARC MANEUVER (SCANDINAVIAN FLICK)
// =====================================================================
void preTurnWideArc(bool isTurningRight) {
  unsigned long arcStart = millis();
  unsigned long maxArcTime = 650; 
  float outerClearanceThreshold = 18.0f; 

  if (isTurningRight) {
    Serial.println("[ARC] Swinging LEFT to widen RIGHT turn...");
    setSteeringDeg(SERVO_MIN_DEG); 
    motorForward(TURN_SPEED);
    
    while (millis() - arcStart < maxArcTime) {
      float distL = readDistanceCM(TRIG_LEFT, ECHO_LEFT);
      if (distL > 0 && distL < outerClearanceThreshold) {
        Serial.printf("[ARC] Left wall close (%.1fcm) - cutting arc short.\n", distL);
        break;
      }
      delay(20);
    }
  } else {
    Serial.println("[ARC] Swinging RIGHT to widen LEFT turn...");
    setSteeringDeg(SERVO_MAX_DEG); 
    motorForward(TURN_SPEED);
    
    while (millis() - arcStart < maxArcTime) {
      float distR = readDistanceCM(TRIG_RIGHT, ECHO_RIGHT);
      if (distR > 0 && distR < outerClearanceThreshold) {
        Serial.printf("[ARC] Right wall close (%.1fcm) - cutting arc short.\n", distR);
        break;
      }
      delay(20);
    }
  }
  
  motorStop();
  delay(150); 
}

// ---------------- Turn decision & execution ----------------
void decideTurn() {
  leftDist  = readDistanceCM(TRIG_LEFT, ECHO_LEFT);
  delay(30);
  rightDist = readDistanceCM(TRIG_RIGHT, ECHO_RIGHT);
  delay(30);

  if (leftDist < 0) leftDist = 999;
  if (rightDist < 0) rightDist = 999;

  TURN++;
  turnStartTime = millis();

  bool isRightTurn = false;

  if (leftDist > rightDist) {
    turnTarget = targetHeading - 90; 
    isRightTurn = false;
  } else {
    turnTarget = targetHeading + 90; 
    isRightTurn = true;
  }

  while (turnTarget < 0)    turnTarget += 360;
  while (turnTarget >= 360) turnTarget -= 360;

  Serial.printf("[TURN %d] L:%.1f R:%.1f | Orthogonal Target: %.1f\n",
                TURN, leftDist, rightDist, turnTarget);

  preTurnWideArc(isRightTurn);

  state = TURNING;
}

void executeTurn() {
  float current = getHeading();
  float diff = headingDiff(turnTarget, current);
  headingError = diff;

  if (fabs(diff) <= TURN_DONE_TOL) {
    motorStop();
    setSteeringDeg(SERVO_CENTER_DEG);
    delay(300); 

    Serial.println("Turn complete. Active-reversing to stabilize, center, and gain vision clearance...");

    unsigned long revStart = millis();
    // INCREASED to 900ms to back up significantly further for vision clarity
    while(millis() - revStart < 900) { 
        float revHeading = getHeading();
        float revErr = headingDiff(turnTarget, revHeading);
        
        float correction = Kp * revErr; 
        int steerDeg = SERVO_CENTER_DEG - constrain((int)correction, -30, 30); 
        
        setSteeringDeg(steerDeg);
        motorBackward(TURN_SPEED);
        delay(20);
    }
    
    motorStop();
    setSteeringDeg(SERVO_CENTER_DEG);
    delay(200);

    targetHeading = turnTarget;
    integral = 0; lastError = 0;
    
    // Wipe latches so vision wakes up fresh
    lastPillarSeenMs = 0; 
    lastTravelUpdateMs = millis();
    
    state = STRAIGHT;
    Serial.printf("[TURN %d] complete, perfectly locked to orthogonal heading: %.1f\n", TURN, targetHeading);
    return;
  }

  int steerDeg = (diff > 0) ? SERVO_MAX_DEG : SERVO_MIN_DEG;
  setSteeringDeg(steerDeg);
  motorForward(TURN_SPEED);
}

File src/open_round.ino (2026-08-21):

// ===================================================================
// WRO Future Engineers - Open Round
//
// ESP32 vehicle: 3x HC-SR04 ultrasonic + BNO055 IMU, servo steering,
// single DC drive motor. Runs 3 laps, then returns to the start.
// Started by a "START" command sent over the USB serial link.
//
// See README.md for wiring, tuning constants and calibration notes.
// ===================================================================

#include <Wire.h>
#include <Adafruit_Sensor.h>
#include <Adafruit_BNO055.h>
#include <utility/imumaths.h>
#include <ESP32Servo.h>
#include <WiFi.h>
#include <WiFiClient.h>
#include <WiFiServer.h>

// ==== PIN Definitions ====
#define PIN_START_BTN 15   // push button, active low

#define PIN_MOTOR_A 13
#define PIN_MOTOR_B 12
#define PIN_MOTOR_PWM 25

#define PIN_STEER 4
#define STEER_FULL_LEFT 25
#define STEER_FULL_RIGHT 145
#define STEER_CENTRE 94    // TODO: trim per car, see README

// Front Ultrasonic
#define PIN_TRIG_F 5
#define PIN_ECHO_F 18

// Right Ultrasonic
#define PIN_TRIG_R 17
#define PIN_ECHO_R 16

// Left Ultrasonic
#define PIN_TRIG_L 26
#define PIN_ECHO_L 27

// ==== Tuning Parameters ====
const int BACKUP_MS = 700;          // TODO: calibrate, should back up ~10cm

// PI controller on heading
float GAIN_P = 6.0;                 // reaction to current error
float GAIN_I = 0.2;                 // removes long-term drift
const float CORRECTION_CAP = 22.0;  // largest steering nudge allowed
const float WINDUP_CAP = 150.0;     // anti-windup limit on the integral
const float SLOP = 0.6;             // error below this counts as straight

// Throttle levels (0-255)
const int PWM_CRUISE = 150;
const int PWM_CORNER = 160;
const int PWM_BACKUP = 120;

// Range thresholds, cm
const float RANGE_BLOCKED = 25.0;   // panic reverse below this
const float RANGE_CORNER = 65.0;    // front wall close enough to turn
const float RANGE_OPEN = 90.0;      // side gap that counts as open
const float HOME_TOLERANCE = 5.0;   // how close to the start line is "home"

// ==== Global Variables ====
Adafruit_BNO055 imu = Adafruit_BNO055(55, 0x28);
Servo steerServo;

// Lap bookkeeping
int cornerCount = 0;
int lapsDone = 0;
int cornersPerLap = 4;              // placeholder, measured on the scouting lap
bool scoutingLap = true;

// State flags
bool homingMode = false;
bool cornering = false;             // disables the PI controller mid-turn

// Heading and position
float headingZero = 0;
float headingSetpoint = 0;
float errorSum = 0;
float homeFrontRange = 0;
bool homeRecorded = false;

// WiFi & Telnet for Debugging
// Fill in your own network before enabling startDebugLink().
const char* WIFI_SSID = "YOUR_WIFI_SSID";
const char* WIFI_PASS = "YOUR_WIFI_PASSWORD";
WiFiServer debugServer(23);
WiFiClient debugClient;

// ==== WiFi and Logging Functions ====
void startDebugLink() {
  WiFi.begin(WIFI_SSID, WIFI_PASS);
  Serial.print("Connecting to WiFi");
  while (WiFi.status() != WL_CONNECTED) {
    delay(500);
    Serial.print(".");
  }
  Serial.println("\nWiFi connected!");
  Serial.print("IP Address: ");
  Serial.println(WiFi.localIP());

  debugServer.begin();
  debugServer.setNoDelay(true);
  Serial.println("Telnet server started");
}

void serviceDebugLink() {
  if (debugServer.hasClient()) {
    if (!debugClient || !debugClient.connected()) {
      if (debugClient) debugClient.stop();
      debugClient = debugServer.available();
      Serial.println("New Telnet client connected");
    } else {
      debugServer.available().stop();
    }
  }
}

void debugLog(String msg) {
  Serial.println(msg);
  if (debugClient && debugClient.connected()) {
    debugClient.println(msg);
  }
}

// ==== Sensor and Motor Functions ====
float pingRange(int trigPin, int echoPin) {
  digitalWrite(trigPin, LOW);
  delayMicroseconds(2);
  digitalWrite(trigPin, HIGH);
  delayMicroseconds(10);
  digitalWrite(trigPin, LOW);
  long echoUs = pulseIn(echoPin, HIGH, 30000);
  if (echoUs == 0) return 999.0;
  float cm = echoUs * 0.034 / 2.0;
  return (cm > 0 && cm < 400) ? cm : 999.0;
}

float readHeading() {
  sensors_event_t imuEvent;
  imu.getEvent(&imuEvent, Adafruit_BNO055::VECTOR_EULER);
  float heading = imuEvent.orientation.x;
  // Convert 0-360 range to -180 to 180 for easier calculations
  if (heading > 180) heading -= 360;
  return heading - headingZero;
}

void motorForward(int pwm) {
  digitalWrite(PIN_MOTOR_A, LOW);
  digitalWrite(PIN_MOTOR_B, HIGH);
  analogWrite(PIN_MOTOR_PWM, pwm);
}

void motorReverse(int pwm) {
  digitalWrite(PIN_MOTOR_A, HIGH);
  digitalWrite(PIN_MOTOR_B, LOW);
  analogWrite(PIN_MOTOR_PWM, pwm);
}

void motorStop() {
  digitalWrite(PIN_MOTOR_A, HIGH);
  digitalWrite(PIN_MOTOR_B, HIGH);
  analogWrite(PIN_MOTOR_PWM, 0);
}

// ==== Navigation Logic ====
void backUpForCorner() {
  debugLog("Reversing before turn...");

  // Drive backward for a fixed duration
  motorReverse(PWM_BACKUP);
  delay(BACKUP_MS);

  // Stop the vehicle and pause briefly to settle before turning
  motorStop();
  delay(200);

  debugLog("Reversing complete. Initiating turn.");
}

void holdHeading(float heading) {
  if (cornering) return; // PI controller is off mid-turn

  float err = headingSetpoint - heading;
  // Handle angle wrap-around
  if (err > 180.0) err -= 360.0;
  if (err < -180.0) err += 360.0;

  // If we're close enough, just go straight
  if (fabs(err) < SLOP) {
    errorSum *= 0.9; // decay the integral slowly
    steerServo.write(STEER_CENTRE);
    return;
  }

  errorSum += err;
  // Prevent integral wind-up
  if (errorSum > WINDUP_CAP) errorSum = WINDUP_CAP;
  if (errorSum < -WINDUP_CAP) errorSum = -WINDUP_CAP;

  float nudge = (GAIN_P * err) + (GAIN_I * errorSum);

  // Clamp the correction value
  if (nudge > CORRECTION_CAP) nudge = CORRECTION_CAP;
  if (nudge < -CORRECTION_CAP) nudge = -CORRECTION_CAP;

  int steerAngle = STEER_CENTRE + (int)round(nudge);
  if (steerAngle < STEER_FULL_LEFT) steerAngle = STEER_FULL_LEFT;
  if (steerAngle > STEER_FULL_RIGHT) steerAngle = STEER_FULL_RIGHT;

  steerServo.write(steerAngle);
}
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

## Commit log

2026-06-09 Add initial test file with hello world print
    test
2026-08-12 Add ESP32 servo control and ultrasonic distance functions V1
2026-08-12 Implement ultrasonic sensor distance reading
    Added ultrasonic sensor reading functionality with setup and loop methods.
2026-08-12 Add ESP32 vehicle control code with navigation logic
    This code implements an ESP32 vehicle control system that uses ultrasonic sensors and an IMU for navigation. It includes functions for motor control, obstacle avoidance, and lap tracking.
2026-08-20 Implement HuskyLens obstacle challenge firmware
    Added firmware for HuskyLens obstacle challenge with ESP32 and various sensors.
2026-08-20 Rename husky lens moutn (1).stl to designs/husky lens moutn (1).stl
    [husky lens moutn (1).stl]
2026-08-20 Rename WRO Future Engineers 2026 — Yo_Bot_To_The_Future — Documentation (HuskyLens rev).docx to docs/Yo_Bot To The Future Documentation.docx
2026-08-20 Rename WRO Future Engineers 2026 — Yo_Bot_To_The_Future — Documentation (HuskyLens rev 2).docx to WRO_YoBotToTheFuture_Documentation
2026-08-20 Rename husky lens moutn (1).stl to husky lens mount (1).stl
    [husky lens mount (1).stl]
2026-08-20 Rename motor mount better (4).stl to motor mount better (4).stl
    [motor mount better (4).stl]
2026-08-20 Rename motor mount better (4).stl to motor mount (4).stl
    [motor mount (4).stl]
